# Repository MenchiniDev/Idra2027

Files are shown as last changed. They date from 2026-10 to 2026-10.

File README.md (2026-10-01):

# Idra di Guerra

Elettronica e meccanica per il carro **"Idra di Guerra"** — Carnevale di Viareggio.

## Obiettivi
- **PCB (KiCad)**: scheda EyeNode per ogni testa (servo degli occhi), alimentazione da 2 × 6 V piombo in serie (12 V).
- **Firmware**: ogni testa muove gli occhi in modo autonomo e casuale, senza sincronia tra le teste.
- **Requisiti elettrici**: budget energetico, dimensionamento alimentatori, sezione cavi, protezioni.
- **Meccanica 3D**: occhi (Ø ≥ 50 mm), incavo/orbita, meccanismo di movimento, supporto servo.
- **Chassis**: contenitori per l'elettronica, cablaggio ordinato e manutenibile.

## Struttura
```
docs/                  requisiti, budget energetico, cablaggio
hardware/kicad/        progetto KiCad (schematico + PCB)
hardware/datasheets/   datasheet componenti
mechanical/eyes/       original/ = modelli sorgente, scaled/ = occhi ingranditi
mechanical/enclosures/ chassis per l'elettronica
mechanical/scripts/    script di generazione/scalatura dei modelli
firmware/              codice delle schede EyeNode (movimento casuale autonomo)
```

## Regola chiave per gli occhi
Il bulbo va ingrandito a **diametro ≥ 50 mm**, ma la **sede del servo resta in scala 1:1**
(i servomotori sono fissi e non cambiano dimensione).

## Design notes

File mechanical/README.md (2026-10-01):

# Meccanica — Occhi animatronici

Base di partenza: **"Animatronic Eyes – Double and Single"** di *MorganManly*
([Instructables](https://www.instructables.com/Animatronic-Eyes-Double-and-Single-Fully-3D-Printe/),
[GitHub](https://github.com/ManlyMorgan/Animatronic-Eye)).
Licenza originale **CC BY-NC-SA 4.0** → vedi `docs/mechanical_eyes.md` § Licenza.

## Cartelle
| Cartella | Contenuto |
|---|---|
| `eyes/original/single_v4` | STL originali occhio singolo (Ø35 mm) |
| `eyes/original/double_compact` | STL originali doppio occhio |
| `eyes/scaled/D50`, `D70`, `D90` | occhi ingranditi Ø50 / Ø70 / Ø90 mm + `info.txt` con quote e viteria |
| `scripts/generate_eyes.py` | generatore parametrico (rigenera tutto, accetta diametri custom) |
| `enclosures/` | chassis elettronica (da fare) |

## Rigenerare
```bash
pip install trimesh manifold3d numpy scipy fast_simplification
python mechanical/scripts/generate_eyes.py          # 50, 70, 90
python mechanical/scripts/generate_eyes.py 60 80    # diametri a scelta
```

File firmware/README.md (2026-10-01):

# Firmware — EyeNode_random

Movimento **autonomo e casuale** degli occhi, uno sketch unico per tutte le teste.
Nessuna sincronizzazione: ogni testa vive per conto suo.

```
firmware/
  EyeNode_random/
    EyeNode_random.ino   logica (non serve toccarla)
    config.h             taratura: calibrazione servo, range, tempi, soglie
  sim/                   simulatore per PC (facoltativo, per provare modifiche senza hardware)
```

## Come rende diverse le teste
All'accensione ogni scheda calcola un **seme casuale** da: indirizzo DIP + contatore di accensioni
salvato in EEPROM + rumore degli ingressi analogici. Dal seme estrae il **carattere** della testa:

| Tratto | Range | Effetto |
|---|---|---|
| velocità | 0.80–1.25 × | quanto sono rapidi gli spostamenti |
| fissazione | 0.70–1.50 × | quanto resta a guardare un punto |
| battiti di ciglia | 0.70–1.40 × | frequenza |
| ampiezza sx/dx, su/giù | `RANGE_*_MIN…MAX` in `config.h` | quanto esplora |
| direzione preferita | ± `BIAS_*_MAX` | dove guarda "di solito" |
| curiosità | 0.25–0.60 | probabilità di grandi spostamenti invece di piccoli |
| convergenza (solo coppie) | 0–0.06 | occhi leggermente strabici verso l'interno |

Poi, ogni 1–4 minuti, cambia **umore**: *calmo* (lento, sguardo stretto), *curioso*, *agitato*
(rapido, fissazioni brevi, occhi sgranati), *assonnato* (palpebre basse, battiti lenti e lunghi).

Movimenti: fissazione con micro-movimenti → saccade (spostamento rapido con frenata finale), a volte
uno spostamento lento di "scansione"; battiti di ciglia casuali, a volte doppi, spesso dopo un grande
spostamento; le palpebre seguono lo sguardo (guardando in basso si abbassano un po').
I due occhi di una coppia guardano nello stesso punto, come occhi veri.

Quindi: due teste non fanno mai la stessa cosa, e la stessa testa a ogni accensione ha un carattere nuovo.

## Caricare il firmware
1. Arduino IDE → scheda **Arduino Nano**, processore **ATmega328P** (sui cloni economici: *Old Bootloader*).
2. Aprire `EyeNode_random/EyeNode_random.ino`, caricare. Librerie: solo `Servo` (inclusa nell'IDE).
3. Impostare il DIP della scheda (ON = 1): Testa 1 `0001`, Testa 2 `0010`, Testa 3 `0011`, Testa 4 `0100`.
   La Testa 4 (occhio singolo) usa solo le uscite A (D3, D5, D6).

Compilato e verificato: 13.4 KB flash (43 %), 713 B RAM (34 %).

## Taratura sul carro (una volta per testa)
1. Aprire il Monitor seriale a **115200**, inviare `c`: tutti i servo vanno al centro e le palpebre aperte.
   In questa posizione si montano squadrette, `LidCrank` e `HornExtender` (servo a 90°).
2. In `config.h`, tabella `CAL[indirizzo][occhio]`, per ogni servo impostare i microsecondi:
   - `lr`/`ud`: `{neg, mid, pos}` = posizione a −1 (sinistra/basso), centro, +1 (destra/alto);
   - `lid`: `{closed, open}`.
   Se un servo va al contrario, scambiare `neg` e `pos`. **Restare dentro la corsa libera**: un servo
   che spinge contro un fermo va in stallo, consuma ~0.8 A e scalda.
3. Ricaricare e inviare `r` per far ripartire il movimento casuale. `b` = battito di ciglia, `s` = stato
   (indirizzo, seme, carattere, umore, tensione servo).

Regolazioni utili in `config.h`:
- `RANGE_*` — ampiezza massima del movimento casuale;
- `FIX_*`, `BLINK_*` — ritmo di sguardi e battiti;
- `SPEED_SCALE` — rallentare tutto per i bulbi grandi (D90: ~0.8);
- `MICRO_AMP = 0` — elimina i micro-movimenti se i servo "ronzano".

## LED blu di stato (D12)
| Lampeggio | Significato |
|---|---|
| N lampi ogni 3 s | funzionamento normale, N = numero della testa |
| acceso fisso | modalità centro (`c`) |
| lampeggio rapido | tensione servo bassa (o batteria bassa, se misurata) |
| un lampo ogni 4 s | batteria scarica: occhi chiusi, servo staccati |

## Misura batteria (opzionale)
Per far "addormentare" la testa a batteria scarica: partitore **47 kΩ / 10 kΩ** dal +12 V al pin A6 del
connettore AUX (J11, pin 4), 10 kΩ verso GND; poi `#define BATT_SENSE_ENABLED 1` in `config.h`.
Soglie (piombo 12 V sotto carico): < 11.9 V umore assonnato, < 11.3 V per 10 s occhi chiusi e servo
staccati, riparte sopra 12.4 V. Non sostituisce il modulo LVD (la logica continua a consumare).

## Simulatore (facoltativo)
`sim/` compila lo stesso sketch sul PC con finti `Servo`/`EEPROM` e scrive le posizioni dei servo in CSV,
così si possono provare modifiche a `config.h` senza hardware. Serve un compilatore C++ (g++, clang o
`pip install ziglang`):
```bash
cd firmware/sim
python -m ziglang c++ -std=c++17 -O2 -w -I. -I../EyeNode_random -x c++ sim.cpp -o sim.exe
./sim.exe 1 123 300 > testa1.csv      # indirizzo, seme di prova, secondi simulati
python plot.py                         # rifà docs/img/simulazione_movimento_teste.png
```

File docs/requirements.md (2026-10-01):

# Requisiti — Idra di Guerra

> Bozza: i valori marcati **TBD** vanno confermati.

## Servomotori
| Voce | Valore |
|---|---|
| Modello servo | MG90S (metal gear) — SG90 sconsigliati |
| N. occhi | 7 (3 coppie + 1 singolo) → 21 servo, 4 schede EyeNode |
| Servo per occhio | 3 (sx/dx, su/giù, palpebre) |
| Tensione nominale | 4.8–6 V (alimentazione servo 6 V da DC-DC) |
| Movimento | autonomo e casuale per ogni testa, nessuna sincronia |
| Corrente di stallo per servo | ~0.7–1 A (da verificare su datasheet del lotto acquistato) |

## Alimentazione
- 2 batterie 6 V piombo **in serie** = 12 V, 30 Ah (AGM/VRLA consigliate).
- Fusibile generale entro 30 cm dal + batteria, fusibile da 5 A per ogni testa, protezione sottotensione.

## Budget energetico
- Corrente di picco = N_servo × I_stallo (dimensionare alimentatore su questo valore + 25% margine).
- Distribuzione per rami con fusibile dedicato.

## Cablaggio
- Sezione cavi in funzione di corrente e lunghezza (caduta di tensione < 3%).
- Connettori bloccabili (vibrazioni del carro), cavi segnale schermati sulle tratte lunghe.

## Ambiente
- Esterno, pioggia/umidità, vibrazioni: contenitori almeno IP54, PCB con conformal coating.

Lista della spesa: [lista_spesa.md](lista_spesa.md)

Dettagli completi (architettura, bilancio energetico, cavi, fusibili): [electronics.md](electronics.md)

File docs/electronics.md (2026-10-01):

# Elettronica — Idra di Guerra

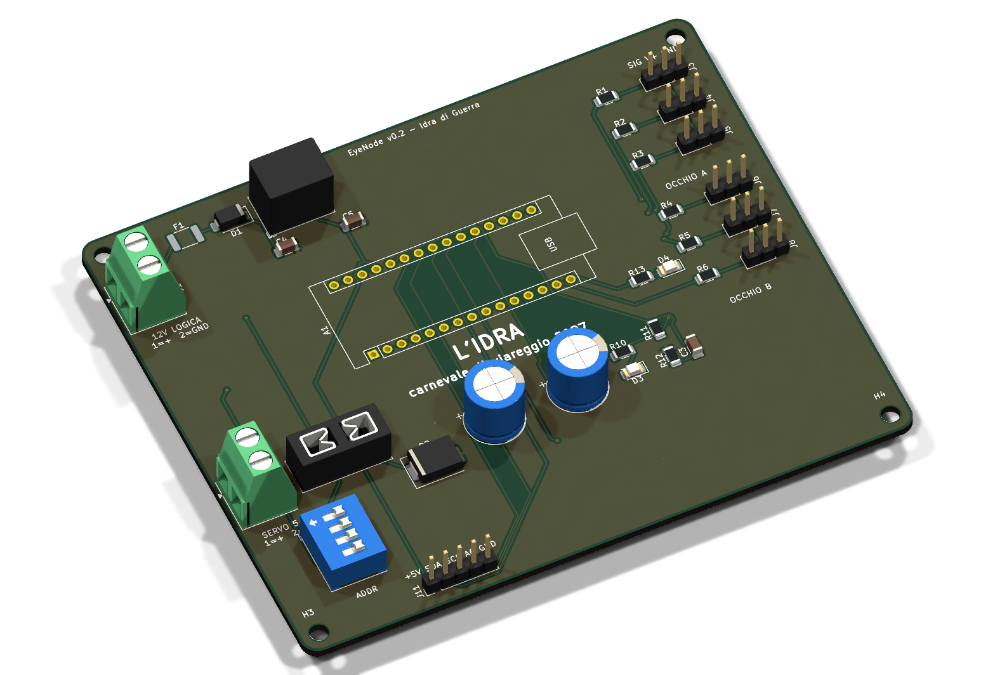
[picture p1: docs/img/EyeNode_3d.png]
EyeNode


## Architettura

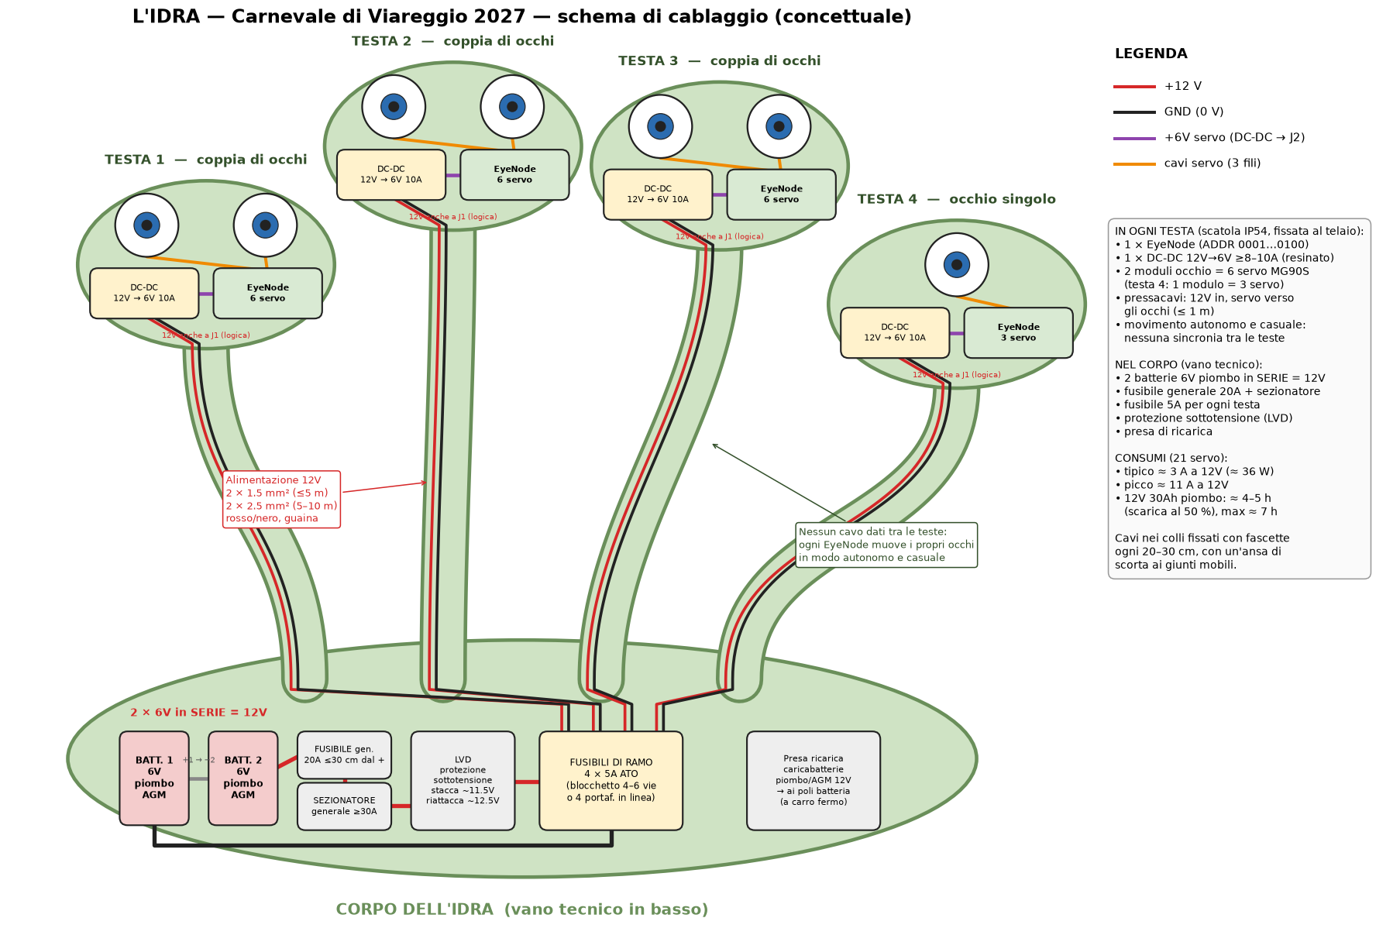
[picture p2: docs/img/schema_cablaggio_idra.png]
Schema di cablaggio


**7 occhi = 3 coppie + 1 singolo = 21 servo MG90S** (3 per occhio: sx/dx, su/giù, palpebre).

Una scheda **EyeNode** per ogni testa, montata vicino agli occhi (cavi servo corti). **Ogni testa è
autonoma**: muove i propri occhi in modo casuale, dentro un range, senza bus dati e senza master.
Il DIP switch serve solo a dire alla scheda quale testa è (coppia o singolo, calibrazione, seme casuale).

| Testa | Occhi | Servo | DIP ADDR |
|---|---|---|---|
| Testa 1 | coppia | 6 | 0001 |
| Testa 2 | coppia | 6 | 0010 |
| Testa 3 | coppia | 6 | 0011 |
| Testa 4 | singolo (solo canali A) | 3 | 0100 |

```
 BATT.1 6V ─(+)──(−)─ BATT.2 6V        ← in SERIE = 12 V
   (−)                    (+)
    │                      └──[F 20A]──[SEZIONATORE]──[LVD]──┬──[F 5A]──> Testa 1
    │                                                       ├──[F 5A]──> Testa 2
    │                                                       ├──[F 5A]──> Testa 3
    └──────────── GND comune ──────────────────────────────  └──[F 5A]──> Testa 4

 In ogni testa:  12V ──> J1 EyeNode (logica, R-78 → 5V)
                 12V ──> DC-DC 12V→6V 10A ──> J2 EyeNode (servo)
```

Perché così:
- **12 V sui cavi lunghi**, conversione a 6 V vicino ai servo: sui cavi lunghi la corrente è circa la metà,
  quindi cadute di tensione e sezioni dei cavi restano contenute.
- **Logica separata dai servo**: l'Arduino ha il suo regolatore (R-78E5.0), quindi i picchi dei servo
  non lo resettano. Le masse sono comuni sulla scheda.
- **Nessuna sincronia**: niente cavo dati nei colli. Un guasto in una testa non tocca le altre.

## Batteria: 2 × 6 V al piombo in serie

> ⚠️ **Serie, non parallelo.** Per ottenere 12 V da due batterie da 6 V vanno collegate **in serie**:
> il **+** della batteria 1 al **−** della batteria 2; si preleva il **−** dalla batteria 1 e il **+** dalla batteria 2.
> In **parallelo** (+ con +, − con −) la tensione resta **6 V** e si raddoppia solo la capacità: con 6 V il
> regolatore della logica (R-78E5.0, minimo 7 V) e i DC-DC 12→6 V non funzionano.
>
> Capacità: in serie la capacità è quella di **una** batteria. Due 6 V **30 Ah** in serie = **12 V 30 Ah**
> (due 6 V 15 Ah in serie farebbero 12 V 15 Ah). I calcoli qui sotto assumono **12 V 30 Ah** totali.

| Voce | Valore |
|---|---|
| Configurazione | 2 × 6 V piombo, **in serie** → 12 V nominali |
| Capacità | 30 Ah (C20) |
| Tipo consigliato | **AGM / VRLA sigillate** (niente acido libero: il carro si inclina e vibra) |
| Tensione utile | 12.7 V carica a riposo · ≈ 12.0 V al 50 % · non scendere sotto ≈ 11.5 V sotto carico |
| Ponticello serie | cavo corto 4 mm² con capicorda, morsetti protetti |
| Ricarica | caricabatterie **12 V piombo/AGM** (assorbimento 14.4–14.7 V, mantenimento 13.6–13.8 V), sulle due in serie |

### Autonomia (stima)
| | Corrente a 12 V | Note |
|---|---|---|
| Consumo tipico (21 servo in movimento casuale + 4 schede) | ≈ 3 A | stima prudente: gran parte del tempo gli occhi sono fermi a fissare |
| Picco (tutti i servo in stallo) | ≈ 11 A | caso limite; 0.37 C, la batteria lo regge |
| Energia utilizzabile al 50 % (consigliato per la durata del piombo) | ≈ 13–15 Ah | → **≈ 4–5 h** |
| Massimo assoluto (80 %) | ≈ 22 Ah | → **≈ 7 h**, ma accorcia molto la vita della batteria |

Regole per il piombo:
- **Ricaricare subito dopo ogni uscita**: lasciata scarica si solfata e perde capacità in pochi giorni.
- Le due batterie devono essere **uguali** (stesso modello, stessa età); in serie, quella più debole si
  scarica per prima. Ogni tanto controllare che le due tensioni siano simili (differenza < 0.1 V a riposo).
- Montarle fisse, in piano, lontano da scintille; le AGM non vanno caricate oltre 14.7 V.
- **Protezione sottotensione (LVD)**: un modulo 12 V da ≥ 20 A che stacca il carico a ≈ 11.5 V e lo
  riattacca a ≈ 12.5 V evita di scaricare a fondo le batterie se il carro resta acceso. In alternativa
  (o in più) il firmware può leggere la batteria su A6 con un partitore (vedi `firmware/README.md`):
  in quel caso a batteria scarica la testa chiude gli occhi e stacca i servo, ma la logica continua a
  consumare qualche decina di mA, quindi non sostituisce l'LVD.

## Serve la scatola dei fusibili?

Risposta breve: **il fusibile generale è obbligatorio, i fusibili per ogni testa sono fortemente consigliati,
la "scatola" è solo il modo più comodo di montarli** — non è indispensabile.

1. **Fusibile generale vicino alla batteria — sì, sempre.** Una batteria al piombo in cortocircuito
   eroga centinaia di ampere: senza fusibile un cavo schiacciato o spellato diventa una resistenza
   incandescente dentro un carro di cartapesta e legno con persone sopra. Va montato entro **30 cm dal
   polo +**, prima di tutto il resto (anche del sezionatore). 20 A per il cavo principale da 4 mm².
2. **Un fusibile per ogni testa — sì, ed ecco perché.** Il fusibile da 20 A protegge il cavo da 4 mm²,
   ma i rami che salgono nei colli sono da 1.5 mm²: un corto lungo un collo potrebbe far passare fino a
   20 A in un cavo da 1.5 mm² chiuso in un fascio, che si scalda ben prima che il 20 A intervenga.
   Il fusibile da 5 A per ramo protegge quel cavo e, in più, **se una testa si guasta si spegne solo
   quella**: le altre tre continuano a muoversi per tutta la sfilata.
3. **Il fusibile sulla scheda (F2, 7.5 A) non basta**: sta *dopo* il DC-DC, quindi protegge il lato 6 V
   dei servo ma non il cavo 12 V che sale nel collo.
4. **Scatola o no?** Con 4 rami bastano 4 **portafusibili in linea stagni** (ATO, pochi euro l'uno). Un
   blocchetto fusibili a 4–6 vie fa la stessa cosa ma è più ordinato: un unico punto da ispezionare,
   ricambi a portata di mano, cablaggio più pulito nel vano tecnico. È una scelta di comodità.
5. L'unico modo di farne a meno sarebbe portare il 4 mm² fino a ogni testa (più rame, più peso, e un
   guasto in una testa spegne tutto). Non conviene.

## Scheda EyeNode v0.2 (`hardware/kicad/EyeNode`)
- 110 × 90 mm, 2 strati, fori M3 agli angoli. **Rame consigliato 2 oz (70 µm)** per le piste servo.
- Arduino Nano v3 su strip femmina (sostituibile, programmabile via USB a bordo).
- 6 uscite servo (header 2.54 mm, ordine **SIG – V+ – GND**, GND verso il bordo):
  `D3 D5 D6` = occhio A (sx/dx, su/giù, palpebre), `D9 D10 D11` = occhio B. Resistenza da 220 Ω in serie su ogni segnale.
- J1: 12 V logica (7–28 V), polyfuse 0.5 A + diodo anti-inversione.
- J2: alimentazione servo 5–6 V, fusibile a lama mini 7.5 A, diodo SS54 di protezione da inversione
  di polarità (fa saltare il fusibile), 2 × 1000 µF.
- VSERVO misurata su A7 (partitore 1:2), LED verde VSERVO, LED blu di stato su D12
  (lampeggia N volte ogni 3 s, N = numero della testa).
- DIP 4 bit su A0–A3 = indirizzo testa. Header AUX: +5V, SDA (A4), SCL (A5), A6, GND
  (A6 = misura batteria opzionale, oppure sensori).
- **v0.2: rimossi MAX485, terminazione 120 Ω, jumper JP1 e morsetti RS-485 IN/OUT** (nessuna sincronia).
  D4, D7, D8 restano liberi.
- Verifiche: ERC 0 errori; DRC 0 errori, 0 connessioni mancanti, parità schema↔PCB ok;
  restano solo 3 avvisi di serigrafia (testo "SERVO 5-6V" vicino al DIP switch).

File di produzione in `hardware/kicad/EyeNode/fab/`: `EyeNode_gerber_JLCPCB.zip` (Gerber + forature),
`EyeNode_BOM.csv`, `EyeNode_pos.csv`, schema PDF, render.

Rigenerare tutto (schema → netlist → PCB → autorouting → piani di massa):
```bash
cd hardware/kicad/scripts
python gen_sch.py
kicad-cli sch export netlist -o ../EyeNode/EyeNode.net ../EyeNode/EyeNode.kicad_sch
"C:/Program Files/KiCad/10.0/bin/python.exe" gen_pcb.py
"C:/Program Files/KiCad/10.0/bin/python.exe" route.py     # Freerouting 2.1 (Java 21)
"C:/Program Files/KiCad/10.0/bin/python.exe" add_logo_text.py
```

## Firmware
`firmware/EyeNode_random/` — stesso sketch su tutte le schede, movimento casuale e indipendente per
ogni testa. Dettagli, taratura e comandi in [firmware/README.md](../firmware/README.md).

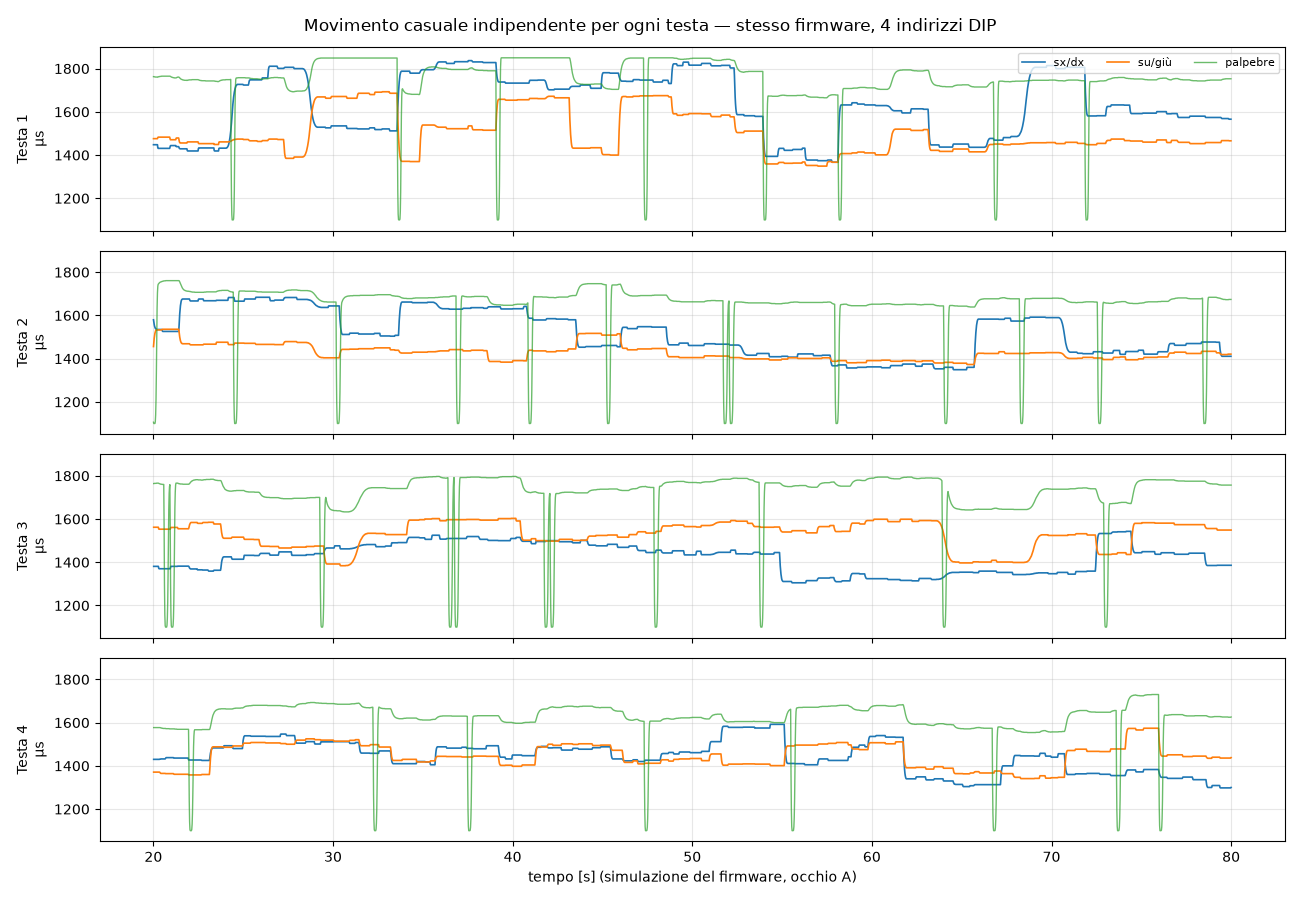
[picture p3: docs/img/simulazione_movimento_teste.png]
Simulazione


## Bilancio energetico
MG90S (datasheet tipico, da verificare sul lotto): ~10 mA a riposo, 150–250 mA in movimento senza carico,
**stallo ~0.7–0.9 A** a 4.8–6 V.

| | Tipico (movimento) | Picco (tutti in stallo) |
|---|---|---|
| 1 servo | 0.25 A | 0.9 A |
| EyeNode coppia (6 servo) | 1.5 A | 5.4 A |
| EyeNode singolo (3 servo) | 0.75 A | 2.7 A |
| **Totale 21 servo, lato 6 V** | **≈ 5 A (30 W)** | **≈ 19 A (113 W)** |
| Totale lato 12 V (η ≈ 90 %, + logica 4 × 50 mA) | ≈ 3 A | ≈ 11 A |

Lo stallo simultaneo di tutti i servo è un caso limite (non accade nel movimento normale), ma
alimentatori e fusibili sono dimensionati comunque per reggerlo. Il firmware aggancia i servo uno alla
volta e fa partire le teste sfasate, così all'accensione non c'è un unico grande spunto.

### Componenti di potenza
| Voce | Specifica | Q.tà |
|---|---|---|
| Batterie | 6 V 30 Ah piombo AGM/VRLA, **collegate in serie** | 2 |
| Ponticello serie | cavo 4 mm² corto con capicorda | 1 |
| Fusibile generale | 20 A a lama ATO/MIDI, portafusibile stagno, **≤ 30 cm dal +** | 1 |
| Sezionatore generale | ≥ 30 A, stagno | 1 |
| Protezione sottotensione (LVD) | 12 V, ≥ 20 A, stacco ≈ 11.5 V / riattacco ≈ 12.5 V | 1 |
| Fusibili di ramo | 5 A ATO: blocchetto 4–6 vie **oppure** 4 portafusibili in linea stagni | 4 |
| DC-DC per testa | 12 V → 6.0 V (oppure 5.0 V), **≥ 8–10 A**, ingresso almeno 9–16 V, resinato/IP67 (tipo automotive) | 4 |
| Fusibile servo sulla scheda | 7.5 A a lama mini (testa singola: 5 A) | 4 |
| Caricabatterie | 12 V piombo/AGM, 3–6 A, con mantenimento | 1 |

### Sezione cavi (rame, caduta di tensione ≤ 5 % andata + ritorno)
| Tratta | Corrente di progetto | Lunghezza | Sezione |
|---|---|---|---|
| Batteria → fusibili di ramo (e ponticello serie) | 11 A | fino a 5 m | **4 mm²** |
| Ramo 12 V → testa | 3 A | ≤ 5 m | **1.5 mm²** |
| Ramo 12 V → testa | 3 A | 5–10 m | **2.5 mm²** |
| DC-DC → J2 (servo) | 6 A | ≤ 0.5 m | **1.5 mm²** |
| Prolunghe servo | 1 A | ≤ 1 m | cavo servo standard 22 AWG (0.33 mm²) |
| Prolunghe servo | 1 A | 1–2 m | 0.5 mm², segnale intrecciato con GND |

Regole di cablaggio: puntalini su tutti i morsetti; connettori bloccabili per le parti mobili del carro;
cavi fissati e protetti nelle zone soggette a vibrazioni; schede in contenitore IP54 con pressacavi.

## Da fare
- [ ] Contenitore stampato 3D per EyeNode + DC-DC (con pressacavi)
- [x] Firmware autonomo casuale (`firmware/EyeNode_random`)
- [ ] Taratura sul carro: limiti meccanici di ogni occhio in `config.h`
- [ ] Verifica corrente di stallo reale dei MG90S acquistati e taratura fusibili
- [ ] Verificare la capacità della singola batteria da 6 V (30 Ah ciascuna → 12 V 30 Ah in serie)

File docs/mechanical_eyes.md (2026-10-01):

# Occhi animatronici ingranditi — note di progetto

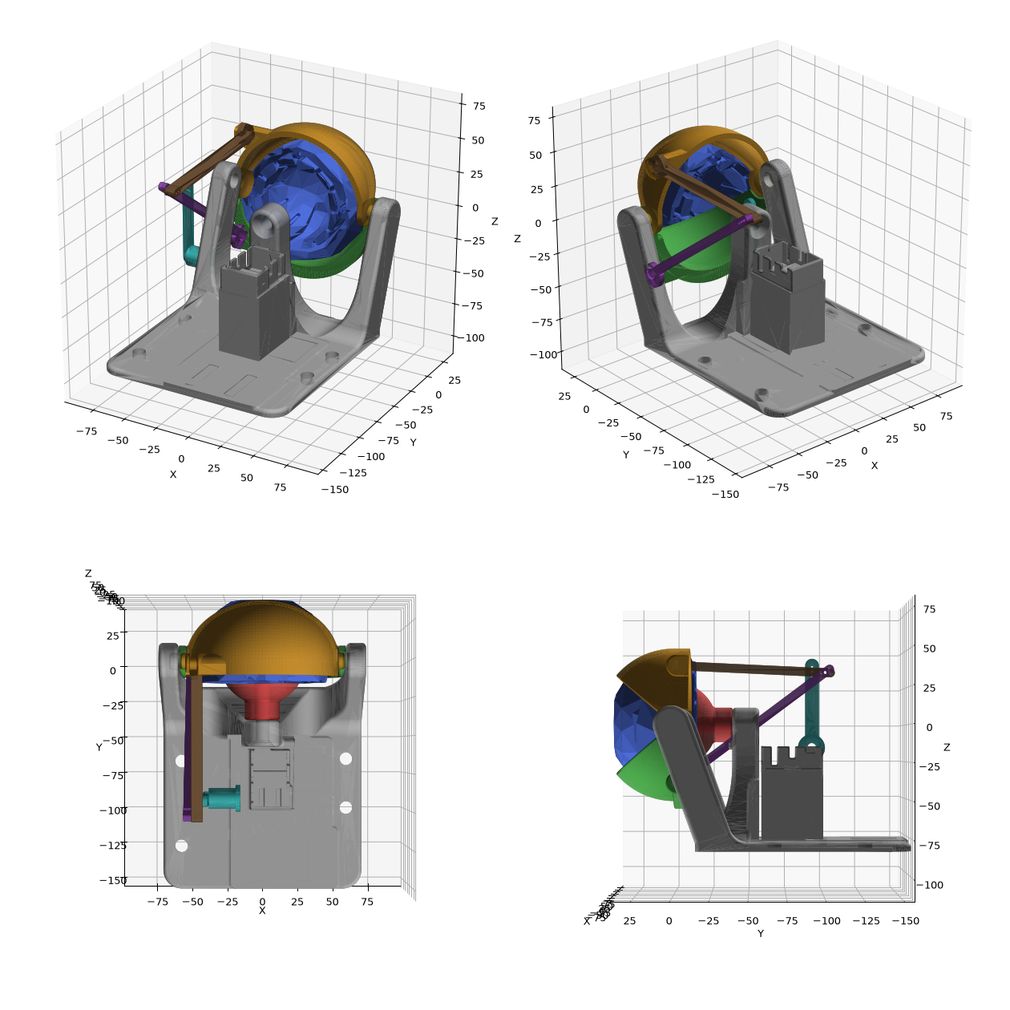
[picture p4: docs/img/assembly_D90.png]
D90


## Cosa viene scalato e cosa no
Fattore `k = D / 35` (D50 → 1.43, D70 → 2.00, D90 → 2.57), centro di scala = centro occhio.

| Pezzo | Trattamento |
|---|---|
| Bulbo, snodo sferico, palpebre sup./inf. | scalati uniformemente di k |
| BasePlate: piastra, montanti palpebre, torre snodo | scalati di k |
| **BasePlate: vano servo** | **1:1 originale**, ritagliato e trapiantato dietro la torre, alla stessa quota rispetto al centro occhio, su un piedistallo |
| Tiranti palpebre | rigenerati: testa d'innesto scalata + corpo dritto + 3 fori di regolazione (±3 mm) |
| `LidCrank` (nuovo) | prolunga per la squadretta del servo palpebre: braccio di raggio k·r, così gli angoli servo restano quelli originali |
| `HornExtender` (nuovo) | prolunga per le squadrette dei 2 servo occhio, fila di fori ogni 2.5 mm per il filo |

Perché le prolunghe: con servo e squadrette 1:1 e leve sull'occhio k volte più grandi, la stessa
corsa del servo darebbe un angolo dell'occhio k volte minore. Allungando il braccio di k la
cinematica torna simile all'originale e la calibrazione (`calibration.ino`) resta valida come punto di partenza.

## Viteria e materiali per taglia
| | D50 | D70 | D90 |
|---|---|---|---|
| Vite snodo (orig. M3) | M4 + inserto M4 | M6 + inserto M6 | M8 + inserto M8 |
| Foro inserto nello snodo | 5.9 mm | 8.2 mm | 10.5 mm |
| Fori fissaggio piastra | 5.0 mm | 7.0 mm | 9.0 mm |
| Filo armonico occhio (orig. 1 mm) | 1.5 mm | 2.0 mm | 2.5 mm |
| Tiranti palpebre ↔ LidCrank | viti M2 | viti M2 | viti M2 |
| Raggio braccio palpebre | 27.9 mm | 39.1 mm | 50.2 mm |
| Ingombro BasePlate (X×Y×Z) | 77×94×53 | 108×131×74 | 138×168×95 |

La zona libera della piastra dietro al vano servo (molto ampia in D70/D90) è pensata per il
fissaggio della scheda di controllo.

## Montaggio — differenze rispetto all'originale
1. Servo, squadrette e vano: identici all'originale (MG90S consigliati).
2. Centrare i servo a 90° **prima** di montare le prolunghe (come da istruzioni originali).
3. `LidCrank`: appoggiarlo sulla squadretta del servo palpebre, forare Ø1.5 attraverso i fori della
   squadretta e fissare con 2 viti M2 autofilettanti; foro centrale Ø6.4 per la vite della squadretta.
   A 90° il braccio deve puntare verso l'alto.
4. Tiranti: una vite M2 lunga attraversa tirante inferiore, tirante superiore e braccio. Scegliere la
   coppia di fori (tirante/braccio) che dà palpebre centrate a servo a 90°.
5. `HornExtender`: stesso fissaggio sulla squadretta; il filo va nel foro al raggio ≈ k × raggio usato in origine.

## Da verificare con la prima stampa (consigliato: D50)
- Asse del servo palpebre stimato da foto e geometria (`LID_SERVO_AXIS` nello script): i fori di
  regolazione compensano ±3 mm, ma va confermato.
- Le tolleranze di stampa si scalano con k (giochi più ampi nelle taglie grandi): verificare
  l'innesto a scatto bulbo–snodo e palpebre–montanti.
- Coppia: con D90 i bulbi pesano ~5-6 volte l'originale; gli MG90S (2.2 kg·cm) restano nel margine
  per movimenti fluidi, ma evitare scatti troppo bruschi (ServoEasing).

## Licenza
Il progetto originale è **CC BY-NC-SA 4.0** (attribuzione, **non commerciale**, condividi allo stesso
modo). I file derivati qui sono soggetti alla stessa licenza. Un carro allegorico ha
un contesto commerciale/professionale: **chiedere il permesso all'autore (MorganManly)** prima dell'uso sul carro,
oppure ridisegnare da zero i pezzi.

## Versione COPPIA (double)
File in `mechanical/eyes/scaled/double/D50|D70|D90/`. Anteprima: `docs/img/confronto_taglie_coppia.png`.

- Base dalla versione "double compact" originale: due vani servo 1:1 (sx e dx speculare), vano
  centrale (supporti protoboard + foro connettore alimentazione) scalato di k.
- Pezzi `_x2` / `_x4` = da stampare 2 / 4 volte (bulbo, snodo, prolunghe squadrette).
- Pezzi `_L` / `_R` = occhio sinistro / destro (palpebre, tiranti, LidCrank speculari).

| | D50 | D70 | D90 |
|---|---|---|---|
| Interasse occhi | 94.0 mm | 131.6 mm | 169.2 mm |
| Ingombro BasePlate_Double (X×Y×Z) | 171×94×53 | 239×131×74 | **308**×168×95 |

⚠️ La BasePlate_Double D90 (308 mm) non entra nei piatti comuni (220–256 mm): va divisa in due
metà con giunzione (posso generarla con incastro a coda di rondine + viti) oppure si usano due
moduli singoli affiancati. La D70 (239 mm) entra in piatti da 256 mm (es. Bambu X1/P1).

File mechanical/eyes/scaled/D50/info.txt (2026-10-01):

diametro_mm: 50
k: 1.4286
spostamento_vano_servo_y_mm: -13.93
asse_servo_palpebre_yz: [-66.93, -15.5]
tirante_sup_mm: 70.5
tirante_inf_mm: 77.4
raggio_braccio_palpebre_mm: 27.9
vite_snodo: M4
inserto_snodo_foro_mm: 5.9
fori_piastra_mm: 5.0
perno_palpebra_mm: 5.7
filo_occhio_mm: 1.5

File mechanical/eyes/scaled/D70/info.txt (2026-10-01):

diametro_mm: 70
k: 2.0
spostamento_vano_servo_y_mm: -26.5
asse_servo_palpebre_yz: [-79.5, -15.5]
tirante_sup_mm: 83.9
tirante_inf_mm: 99.0
raggio_braccio_palpebre_mm: 39.1
vite_snodo: M6
inserto_snodo_foro_mm: 8.2
fori_piastra_mm: 7.0
perno_palpebra_mm: 8.0
filo_occhio_mm: 2.0

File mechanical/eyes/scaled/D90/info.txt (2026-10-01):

diametro_mm: 90
k: 2.5714
spostamento_vano_servo_y_mm: -39.07
asse_servo_palpebre_yz: [-92.07, -15.5]
tirante_sup_mm: 97.4
tirante_inf_mm: 121.4
raggio_braccio_palpebre_mm: 50.2
vite_snodo: M8
inserto_snodo_foro_mm: 10.5
fori_piastra_mm: 9.0
perno_palpebra_mm: 10.3
filo_occhio_mm: 2.5

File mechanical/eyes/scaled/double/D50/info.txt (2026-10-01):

diametro_mm: 50
k: 1.4286
interasse_occhi_mm: 94.0
spostamento_vani_servo_y_mm: -13.93
tirante_sup_mm: 70.5
tirante_inf_mm: 77.4
raggio_braccio_palpebre_mm: 27.9
vite_snodo: M4
inserto_snodo_foro_mm: 5.9
fori_piastra_mm: 5.0
perno_palpebra_mm: 5.7
filo_occhio_mm: 1.5

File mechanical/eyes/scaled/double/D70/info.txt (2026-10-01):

diametro_mm: 70
k: 2.0
interasse_occhi_mm: 131.6
spostamento_vani_servo_y_mm: -26.5
tirante_sup_mm: 83.9
tirante_inf_mm: 99.0
raggio_braccio_palpebre_mm: 39.1
vite_snodo: M6
inserto_snodo_foro_mm: 8.2
fori_piastra_mm: 7.0
perno_palpebra_mm: 8.0
filo_occhio_mm: 2.0

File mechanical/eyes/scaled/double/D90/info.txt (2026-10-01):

diametro_mm: 90
k: 2.5714
interasse_occhi_mm: 169.2
spostamento_vani_servo_y_mm: -39.07
tirante_sup_mm: 97.4
tirante_inf_mm: 121.4
raggio_braccio_palpebre_mm: 50.2
vite_snodo: M8
inserto_snodo_foro_mm: 10.5
fori_piastra_mm: 9.0
perno_palpebra_mm: 10.3
filo_occhio_mm: 2.5

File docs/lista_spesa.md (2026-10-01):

# Lista della spesa — L'Idra 2027

Per 4 teste (3 coppie + 1 singolo = 7 occhi, 21 servo), alimentazione 2 × 6 V piombo in serie.
Le quantità includono già qualche **ricambio** (colonna "di cui ricambi").
Prezzi = **stima indicativa** in €, IVA inclusa, da negozi online tipo Amazon/AliExpress/elettronica
generica: servono per farsi un'idea del budget, non sono preventivi.

> **Cavi: lunghezze stimate.** Ho assunto ≤ 5 m dal vano tecnico a ogni testa. Prima di comprare
> misurare il percorso reale di ogni collo (+ 1 m di scorta). Se un collo supera i 5 m, quel ramo va
> in 2 × 2.5 mm² invece di 2 × 1.5 mm².

## 1. Alimentazione (vano tecnico nel corpo)
| # | Articolo | Specifica | Q.tà | di cui ricambi | € stima |
|---|---|---|---|---|---|
| 1 | Batterie | 6 V 30 Ah piombo AGM/VRLA, **già disponibili** — da collegare in **serie** | 2 | — | — |
| 2 | Portafusibile generale stagno | per fusibile a lama ATO (o MIDI), con cavo 4 mm² | 1 | — | 6–10 |
| 3 | Fusibili ATO 20 A | lama standard | 3 | 2 | 3 |
| 4 | Sezionatore generale | stacca-batteria rotativo ≥ 30 A, stagno | 1 | — | 15–25 |
| 5 | Modulo LVD (protezione sottotensione) | 12 V, ≥ 20 A, stacco ~11.5 V / riattacco ~12.5 V, regolabile | 1 | — | 15–25 |
| 6 | Blocco fusibili | 6 vie ATO **con barra negativa integrata** e coperchio (tipo nautico) — *oppure* 4 portafusibili ATO in linea stagni | 1 | — | 15–25 |
| 7 | Fusibili ATO 5 A | rami verso le teste | 8 | 4 | 3 |
| 8 | Caricabatterie | 12 V piombo/AGM, 3–6 A, con mantenimento | 1 | — | 30–50 |
| 9 | Presa di ricarica (opz.) | presa stagna 2 poli (tipo SAE o Anderson 50 A) da pannello | 1 | — | 5–10 |
| 10 | Scatola vano tecnico | IP65 ~300 × 200 × 150 mm, o cassetta batterie con cinghie | 1 | — | 20–35 |

## 2. Elettronica in ogni testa
| # | Articolo | Specifica | Q.tà | di cui ricambi | € stima |
|---|---|---|---|---|---|
| 11 | Convertitore DC-DC | 12 V → 6 V, **≥ 10 A**, ingresso almeno 9–16 V, resinato/impermeabile | 5 | 1 | 50–75 |
| 12 | Servo MG90S | **metal gear** (non SG90) | 25 | 4 | 75–100 |
| 13 | Prolunghe servo | 3 fili JR/Futaba, 30–50 cm (misurare dalla scheda agli occhi) | 25 | 4 | 10–15 |
| 14 | Fusibili a lama **mini** 7.5 A | per F2 sulla scheda (teste 1–3) | 6 | 3 | 2 |
| 15 | Fusibili a lama **mini** 5 A | per F2 sulla scheda (testa 4) | 2 | 1 | 1 |
| 16 | Scatola per scheda + DC-DC | IP65 ~150 × 120 × 70 mm (o contenitore stampato 3D) | 4 | — | 25–40 |
| 17 | Pressacavi | PG7 (cavi servo) + PG9 (alimentazione), kit assortito | 1 kit | — | 8 |
| 18 | Morsetti a leva Wago 221-413 | per dividere il 12 V tra DC-DC e J1 nella testa | 10 | 2 | 6 |

## 3. Scheda EyeNode (componenti per 5 schede: 4 + 1 ricambio)
| # | Articolo | Rif. | Footprint / tipo | Q.tà | € stima |
|---|---|---|---|---|---|
| 19 | PCB EyeNode v0.2 | — | JLCPCB, 2 strati, **rame 2 oz**, 110 × 90 mm (file `fab/EyeNode_gerber_JLCPCB.zip`) | 5 (minimo ordine) | 25–45 con spedizione |
| 20 | Arduino Nano v3 | A1 | ATmega328P, USB mini-B o C | 5 | 25–40 |
| 21 | Strip femmina 1 × 15, passo 2.54 | per A1 | per rendere il Nano estraibile | 10 | 3 |
| 22 | Regolatore RECOM R-78E5.0-0.5 | U1 | THT SIP3 | 5 | 20 |
| 23 | Condensatore elettrolitico 1000 µF **16 V** low-ESR | C1, C2 | radiale Ø10 mm, passo 5 mm | 10 | 5 |
| 24 | Condensatore ceramico 100 nF | C3 | SMD 1206 | 10 | 1 |
| 25 | Condensatore ceramico 10 µF 50 V | C4 | SMD 1206 | 10 | 2 |
| 26 | Condensatore ceramico 10 µF 16 V | C5 | SMD 1206 | 10 | 1 |
| 27 | Diodo Schottky SS34 | D1 | SMA | 10 | 1 |
| 28 | Diodo Schottky SS54 | D2 | SMC | 10 | 2 |
| 29 | LED verde | D3 | SMD 1206 | 10 | 1 |
| 30 | LED blu | D4 | SMD 1206 | 10 | 1 |
| 31 | Polyfuse 0.5 A | F1 | SMD 1812 | 10 | 2 |
| 32 | Portafusibile lama mini Keystone 3568 | F2 | THT | 5 | 6 |
| 33 | Morsetto a vite 2 poli passo 5.08 (Phoenix MKDS 1,5/2) | J1, J2 | THT | 10 | 4 |
| 34 | Strip maschio 1 × 40, passo 2.54 | J3–J8, J11 | da tagliare a 3 e 5 pin | 5 | 2 |
| 35 | Resistenza 220 Ω | R1–R6 | SMD 1206 | 50 | 1 |
| 36 | Resistenza 1 kΩ | R10, R13 | SMD 1206 | 20 | 1 |
| 37 | Resistenza 10 kΩ | R11, R12 | SMD 1206 | 20 | 1 |
| 38 | DIP switch 4 vie | SW1 | THT passo 2.54 | 5 | 3 |
| 39 | Distanziali M3 10 mm + viti | fori angoli | nylon o ottone | 20 | 4 |

*Facoltativo, misura batteria nel firmware:* resistenze 47 kΩ e 10 kΩ (¼ W), 5 + 5.
*Alternativa:* far montare i componenti SMD direttamente a JLCPCB (servizio di assemblaggio) usando
`EyeNode_BOM.csv` e `EyeNode_pos.csv`; restano da saldare a mano solo i componenti a foro passante.

## 4. Cavi e materiale di cablaggio
| # | Articolo | Specifica | Q.tà | Uso | € stima |
|---|---|---|---|---|---|
| 40 | Cavo unipolare **4 mm²** rosso | flessibile (FS17/H07V-K) | 3 m | batteria → fusibile → sezionatore → LVD → blocco fusibili | 5 |
| 41 | Cavo unipolare **4 mm²** nero | flessibile | 3 m | ritorno negativo + **ponticello serie** tra le batterie | 5 |
| 42 | Cavo bipolare **2 × 1.5 mm²** rosso/nero | piattina o cavo con guaina (FROR) | 25 m | 4 rami da ~5 m verso le teste + DC-DC → J2 | 25–35 |
| 43 | Cavo bipolare 2 × 2.5 mm² | solo se un collo supera 5 m | a misura | ramo lungo | — |
| 44 | Cavo 3 × 0.5 mm² (o prolunghe servo da 1–2 m) | solo se un servo è a più di 1 m dalla scheda | a misura | prolunghe lunghe | — |
| 45 | Capicorda ad occhiello 4 mm² | foro adatto ai poli batteria e al sezionatore (M5/M6/M8, verificare) | 10 | poli batteria, sezionatore | 3 |
| 46 | Faston femmina isolati 6.3 mm, 4 mm² | solo se le batterie hanno poli faston | 6 | poli batteria | 2 |
| 47 | Puntalini isolati | kit assortito 0.5 – 4 mm² | 1 kit | tutti i morsetti a vite | 8 |
| 48 | Connettori stagni 2 poli, maschio + femmina | tipo Superseal / Deutsch DT, per 1.5 mm² | 5 coppie | staccare ogni testa alla base del collo | 12–20 |
| 49 | Guaina termorestringente | kit assortito, con colla | 1 kit | giunzioni e connettori | 8 |
| 50 | Tubo corrugato spiralato | Ø 10–13 mm | 20 m | protezione cavi nei colli | 10–15 |
| 51 | Fascette | 200 mm + 300 mm, nere anti-UV | 200 | fissaggio cavi ogni 20–30 cm | 6 |
| 52 | Basette per fascette | adesive o a vite | 50 | punti di fissaggio sul telaio | 5 |
| 53 | Cavo USB (mini-B o C, come i Nano) | — | 1 | programmazione | 3 |

## 5. Meccanica occhi (dipende dalla taglia scelta)
| # | Articolo | D50 | D70 | D90 | Q.tà |
|---|---|---|---|---|---|
| 54 | Filamento PETG (o PLA+) | ~1 kg | ~2 kg | ~3 kg | — |
| 55 | Vite snodo + inserto filettato a caldo | M4 | M6 | M8 | 7 + 3 ricambi |
| 56 | Filo armonico (acciaio) per tiranti occhio | Ø 1.5 mm | Ø 2.0 mm | Ø 2.5 mm | 2 m |
| 57 | Viti M2 autofilettanti 8–12 mm | per LidCrank, HornExtender, tiranti palpebre | | | 100 |
| 58 | Viti fissaggio piastre al telaio | Ø foro 5 / 7 / 9 mm | | | 30 |

## Riepilogo budget indicativo
| Gruppo | € stima |
|---|---|
| 1. Alimentazione (batterie escluse) | ~110–185 |
| 2. Elettronica teste | ~175–245 |
| 3. Scheda EyeNode × 5 | ~110–150 |
| 4. Cavi e cablaggio | ~90–115 |
| 5. Meccanica (D70) | ~50–80 |
| **Totale** | **~545–775 €** |

## Attrezzi (se mancano)
Saldatore con punta fine + stagno 0.5 mm e flussante; **crimpatrice** per capicorda e puntalini;
spelafili; pistola termica; multimetro; stampante 3D.

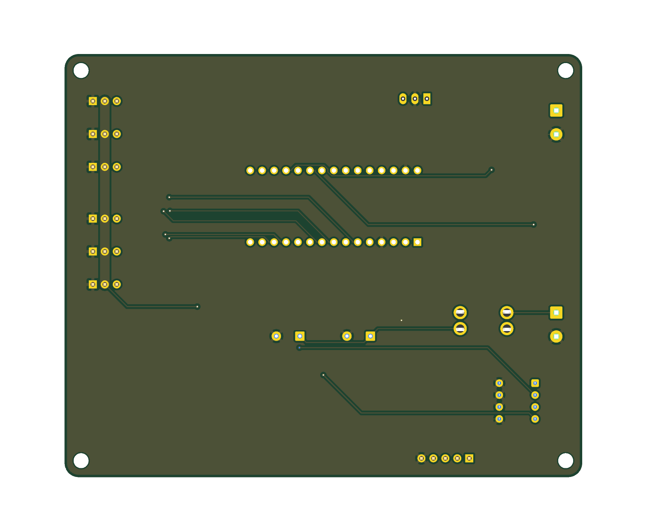
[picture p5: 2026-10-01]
hardware/kicad/EyeNode/fab/EyeNode_bottom.png

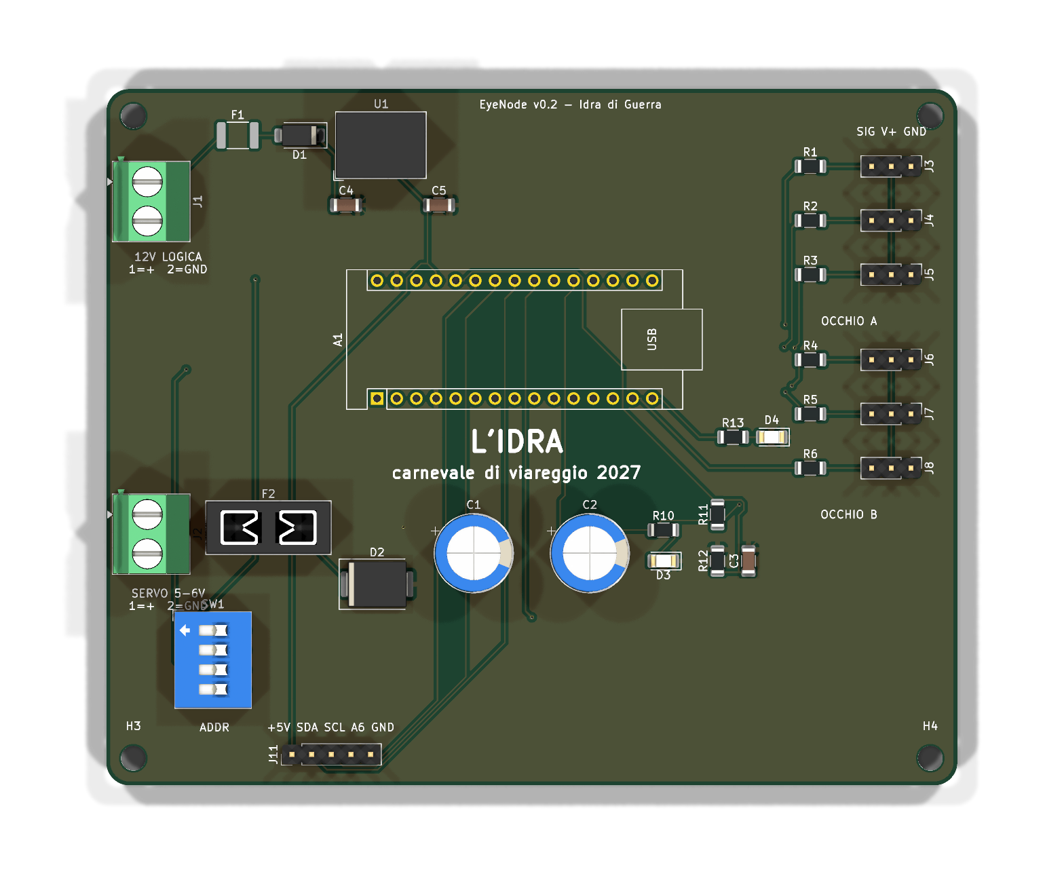
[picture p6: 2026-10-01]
hardware/kicad/EyeNode/fab/EyeNode_top.png

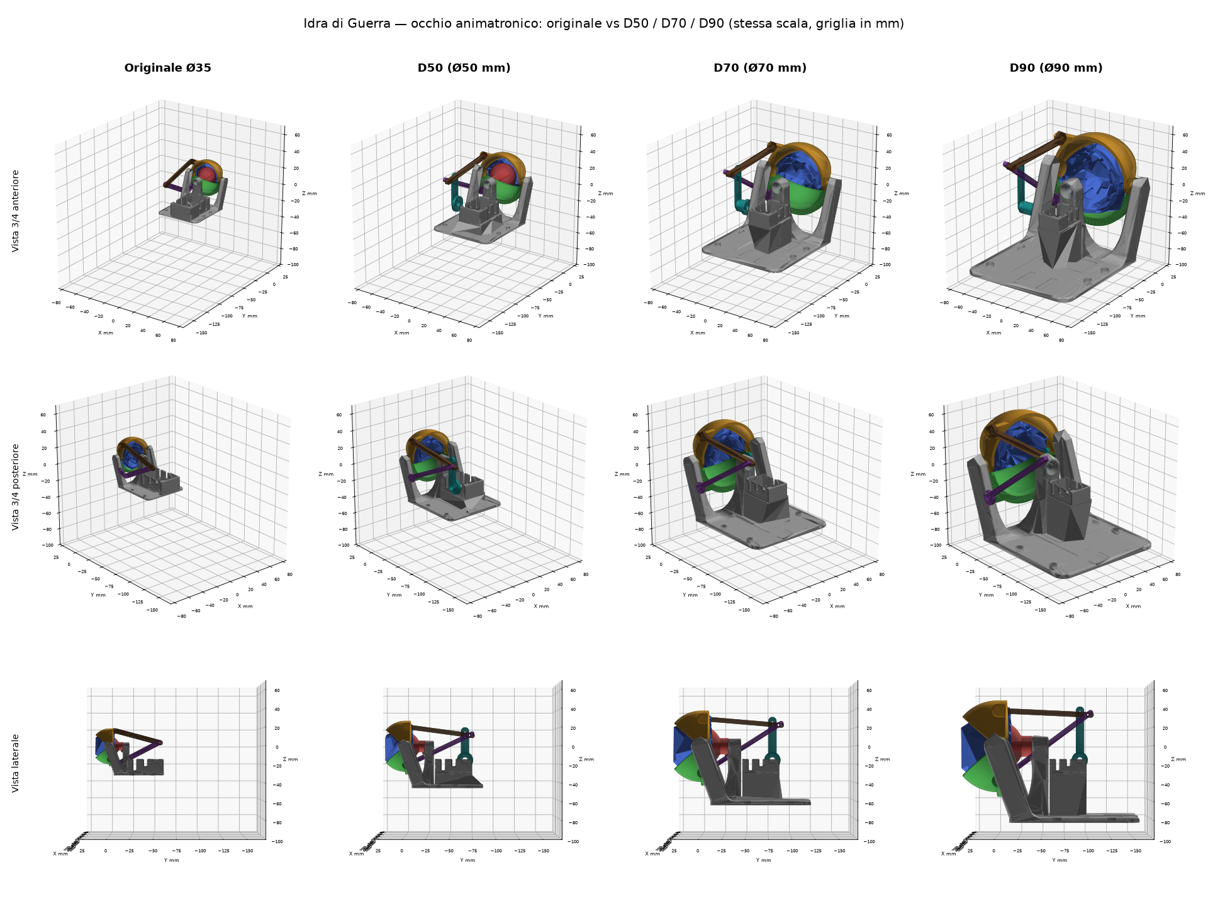
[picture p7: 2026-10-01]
docs/img/confronto_taglie.png

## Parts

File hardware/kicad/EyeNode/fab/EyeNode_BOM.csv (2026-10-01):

Riferimenti | Valore | Footprint | Qta
A1 | Arduino Nano v3 | Module:Arduino_Nano | 1
C1,C2 | 1000uF 10V | Capacitor_THT:CP_Radial_D10.0mm_P5.00mm | 2
C3 | 100nF | Capacitor_SMD:C_1206_3216Metric | 1
C4 | 10uF 50V | Capacitor_SMD:C_1206_3216Metric | 1
C5 | 10uF 16V | Capacitor_SMD:C_1206_3216Metric | 1
D1 | SS34 | Diode_SMD:D_SMA | 1
D2 | SS54 (crowbar inv. pol.) | Diode_SMD:D_SMC | 1
D3 | verde VSERVO | LED_SMD:LED_1206_3216Metric | 1
D4 | blu STATO | LED_SMD:LED_1206_3216Metric | 1
F1 | 0.5A | Fuse:Fuse_1812_4532Metric | 1
F2 | 7.5A blade | Fuse:Fuseholder_Blade_Mini_Keystone_3568 | 1
J1 | 12V IN logica | TerminalBlock_Phoenix:TerminalBlock_Phoenix_MKDS-1,5-2-5.08_1x02_P5.08mm_Horizontal | 1
J2 | 5-6V IN servo | TerminalBlock_Phoenix:TerminalBlock_Phoenix_MKDS-1,5-2-5.08_1x02_P5.08mm_Horizontal | 1
J3 | SERVO A_LR | Connector_PinHeader_2.54mm:PinHeader_1x03_P2.54mm_Vertical | 1
J4 | SERVO A_UD | Connector_PinHeader_2.54mm:PinHeader_1x03_P2.54mm_Vertical | 1
J5 | SERVO A_LID | Connector_PinHeader_2.54mm:PinHeader_1x03_P2.54mm_Vertical | 1
J6 | SERVO B_LR | Connector_PinHeader_2.54mm:PinHeader_1x03_P2.54mm_Vertical | 1
J7 | SERVO B_UD | Connector_PinHeader_2.54mm:PinHeader_1x03_P2.54mm_Vertical | 1
J8 | SERVO B_LID | Connector_PinHeader_2.54mm:PinHeader_1x03_P2.54mm_Vertical | 1
J11 | AUX I2C/A6 | Connector_PinHeader_2.54mm:PinHeader_1x05_P2.54mm_Vertical | 1
R1-R6 | 220 | Resistor_SMD:R_1206_3216Metric | 6
R10,R13 | 1k | Resistor_SMD:R_1206_3216Metric | 2
R11,R12 | 10k | Resistor_SMD:R_1206_3216Metric | 2
SW1 | ADDR | Button_Switch_THT:SW_DIP_SPSTx04_Slide_9.78x12.34mm_W7.62mm_P2.54mm | 1
U1 | R-78E5.0-0.5 | Converter_DCDC:Converter_DCDC_RECOM_R-78E-0.5_THT | 1

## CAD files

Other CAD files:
mechanical/eyes/original/double_compact/Animatronic Eyes - Eyelid_Lower_R.stl
mechanical/eyes/original/single_v4/Animatronic Eyes - Eyelid_Lower_L.stl
mechanical/eyes/scaled/D50/EyeBall_Ball_Joint_D50.stl
mechanical/eyes/scaled/D70/BasePlate_D70.stl
mechanical/eyes/scaled/D90/BasePlate_D90.stl
mechanical/eyes/scaled/double/D50/Linkage_Lower_L_D50.stl
mechanical/eyes/scaled/double/D70/EyeBall_Ball_Joint_D70_x2.stl
mechanical/eyes/scaled/double/D90/EyeBall_Ball_Joint_D90_x2.stl
mechanical/eyes/original/double_compact/Animatronic Eyes - BasePlate.stl
mechanical/eyes/original/single_v4/Animatronic Eyes - Eyelid_Upper_L.stl
mechanical/eyes/scaled/D50/Linkage_Lower_D50.stl
mechanical/eyes/scaled/D70/Linkage_Upper_D70.stl
mechanical/eyes/scaled/D90/EyeBall_Ball_Joint_D90.stl
mechanical/eyes/scaled/double/D50/Linkage_Upper_R_D50.stl
mechanical/eyes/scaled/double/D70/Linkage_Lower_R_D70.stl
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

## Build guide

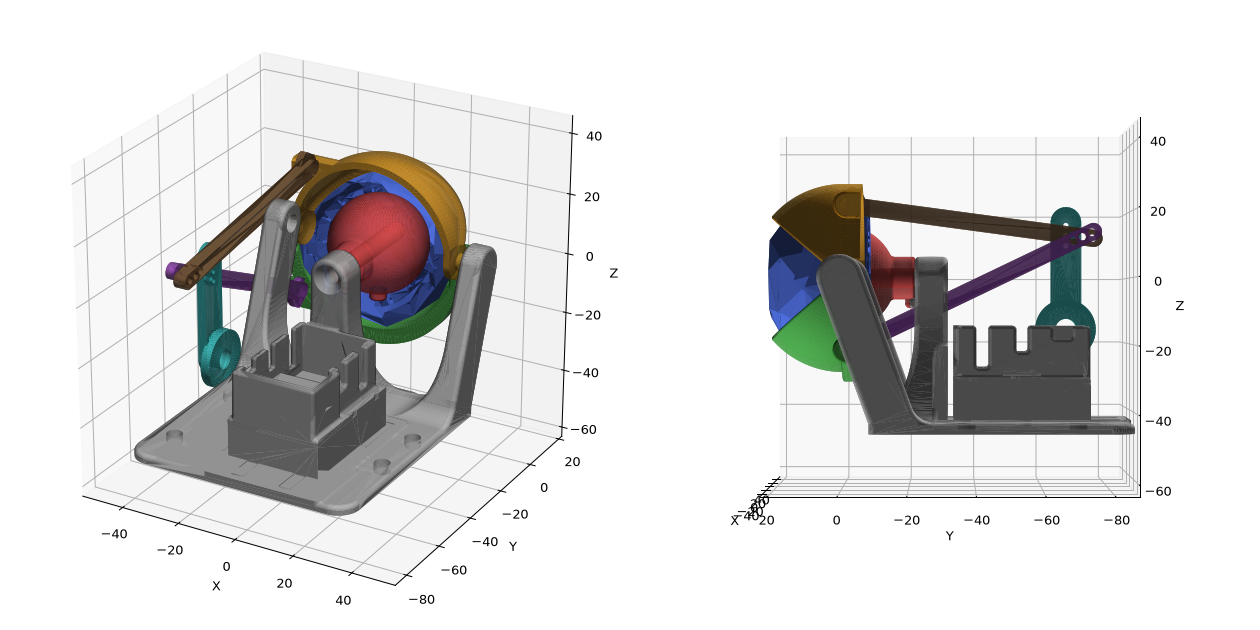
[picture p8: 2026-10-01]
docs/img/assembly_D50.png

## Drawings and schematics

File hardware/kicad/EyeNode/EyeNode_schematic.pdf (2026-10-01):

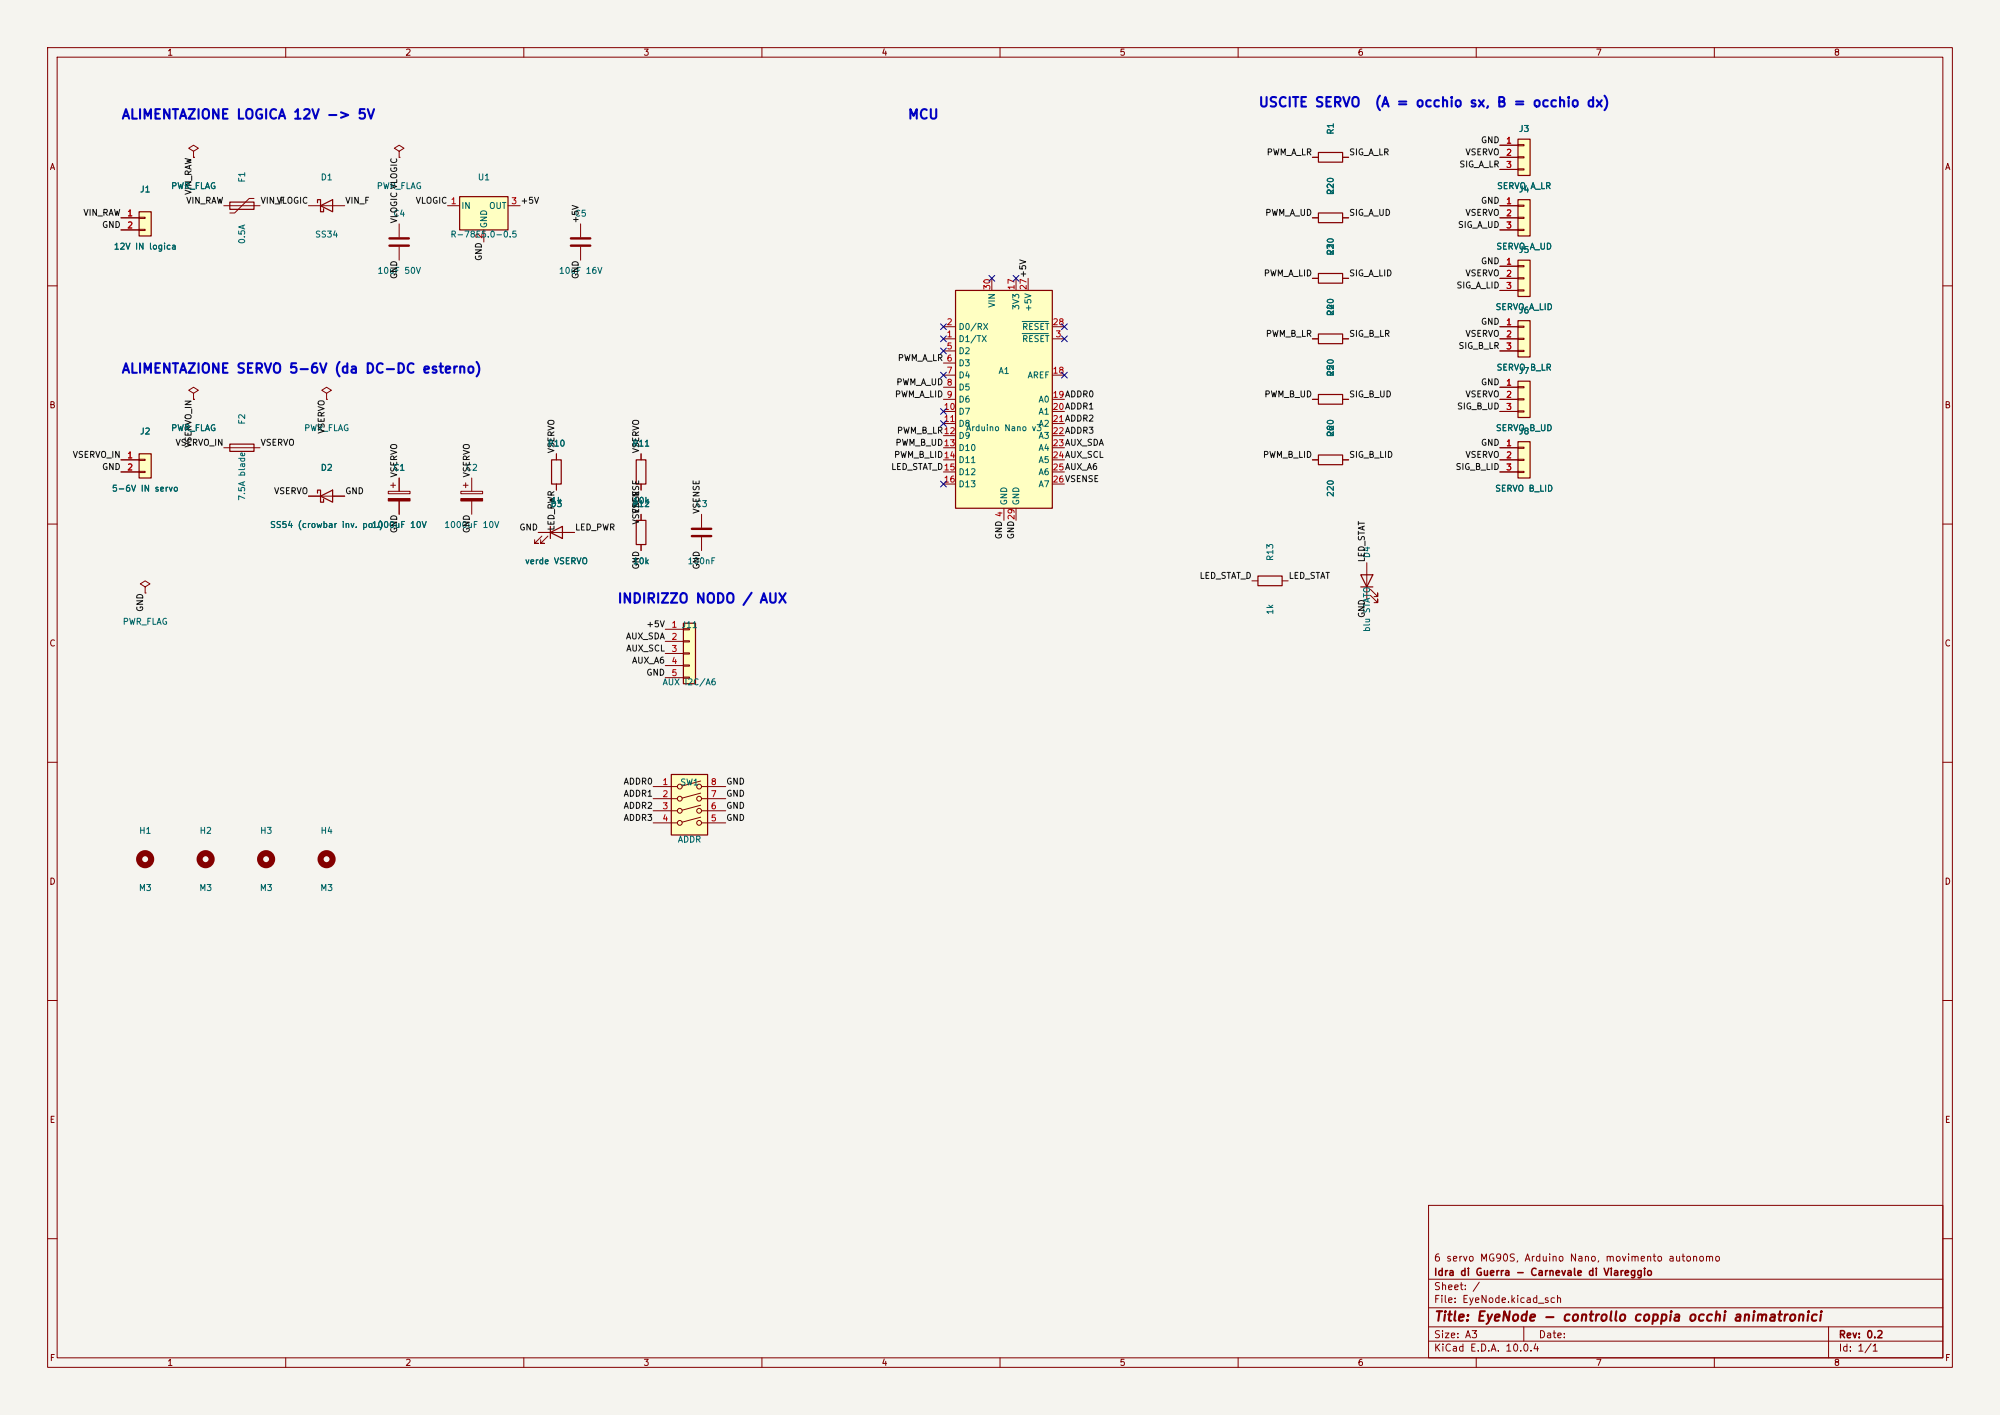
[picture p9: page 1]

USCITE SERVO (A = occhio sx, B = occhio dx)

ALIMENTAZIONE SERVO 5-6V (da DC-DC esterno)

6 servo MG90S, Arduino Nano, movimento autonomo
Idra di Guerra - Carnevale di Viareggio
Sheet: /
File: EyeNode.kicad_sch
Title: EyeNode - controllo coppia occhi animatronici

Size: A3 | Rev: 0.2
KiCad E.D.A. 10.0.4 | Id: 1/1 | F Date:

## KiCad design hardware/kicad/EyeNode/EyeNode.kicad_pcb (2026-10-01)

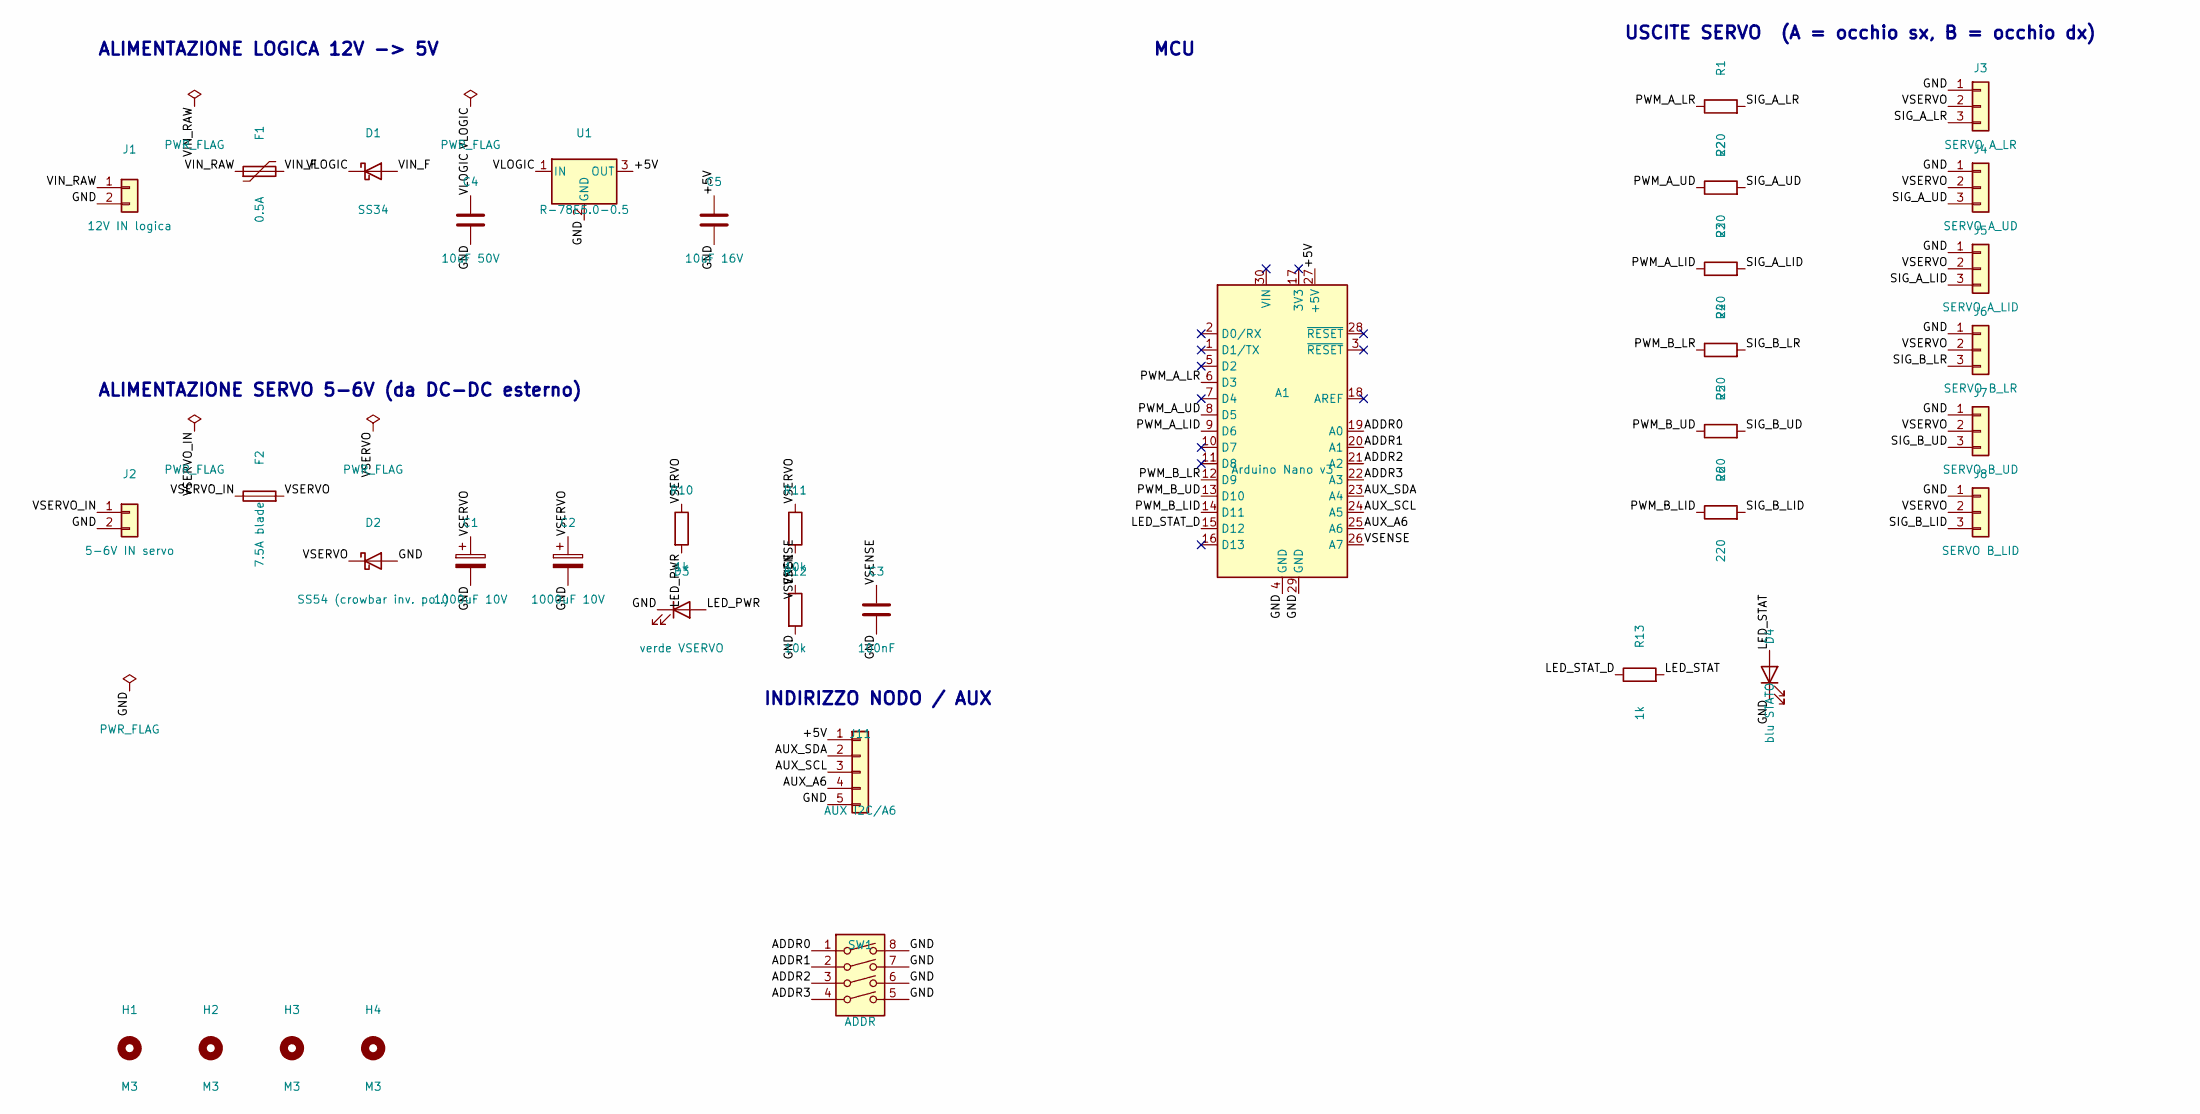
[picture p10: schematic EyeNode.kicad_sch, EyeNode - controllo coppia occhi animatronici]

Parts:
A1: Arduino Nano v3; Arduino_Nano
C1, C2: 1000uF 10V; CP_Radial_D10.0mm_P5.00mm
C3: 100nF; C_1206_3216Metric
C4: 10uF 50V; C_1206_3216Metric
C5: 10uF 16V; C_1206_3216Metric
D1: SS34; D_SMA
D2: SS54 (crowbar inv. pol.); D_SMC
D3: verde VSERVO; LED_1206_3216Metric
D4: blu STATO; LED_1206_3216Metric
F1: 0.5A; Fuse_1812_4532Metric
F2: 7.5A blade; Fuseholder_Blade_Mini_Keystone_3568
H1, H2, H3, H4: M3; MountingHole_3.2mm_M3
J1: 12V IN logica; TerminalBlock_Phoenix_MKDS-1,5-2-5.08_1x02_P5.08mm_Horizont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
J2: 5-6V IN servo; TerminalBlock_Phoenix_MKDS-1,5-2-5.08_1x02_P5.08mm_Horizont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
J3: SERVO A_LR; PinHeader_1x03_P2.54mm_Vertical
J4: SERVO A_UD; PinHeader_1x03_P2.54mm_Vertical
J5: SERVO A_LID; PinHeader_1x03_P2.54mm_Vertical
J6: SERVO B_LR; PinHeader_1x03_P2.54mm_Vertical
J7: SERVO B_UD; PinHeader_1x03_P2.54mm_Vertical
J8: SERVO B_LID; PinHeader_1x03_P2.54mm_Vertical
J11: AUX I2C/A6; PinHeader_1x05_P2.54mm_Vertical
R1, R2, R3, R4, R5, R6: 220; R_1206_3216Metric
R10, R13: 1k; R_1206_3216Metric
R11, R12: 10k; R_1206_3216Metric
SW1: ADDR; SW_DIP_SPSTx04_Slide_9.78x12.34mm_W7.62mm_P2.54mm
U1: R-78E5.0-0.5; Converter_DCDC_RECOM_R-78E-0.5_THT

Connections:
/+5V: A1.27 (+5V), C5.1, J11.1, U1.3 (OUT)
/ADDR0: A1.19 (A0), SW1.1
/ADDR1: A1.20 (A1), SW1.2
/ADDR2: A1.21 (A2), SW1.3
/ADDR3: A1.22 (A3), SW1.4
/AUX_A6: A1.25 (A6), J11.4
/AUX_SCL: A1.24 (A5), J11.3
/AUX_SDA: A1.23 (A4), J11.2
/GND: A1.4 (GND), A1.29 (GND), C1.2, C2.2, C3.2, C4.2, C5.2, D2.2 (A), D3.1 (K), D4.1 (K), J1.2, J2.2, J3.1, J4.1, J5.1, J6.1, J7.1, J8.1, J11.5, R12.2, SW1.5, SW1.6, SW1.7, SW1.8, U1.2 (GND)
/LED_PWR: D3.2 (A), R10.2
/LED_STAT: D4.2 (A), R13.2
/LED_STAT_D: A1.15 (D12), R13.1
/PWM_A_LID: A1.9 (D6), R3.1
/PWM_A_LR: A1.6 (D3), R1.1
/PWM_A_UD: A1.8 (D5), R2.1
/PWM_B_LID: A1.14 (D11), R6.1
/PWM_B_LR: A1.12 (D9), R4.1
/PWM_B_UD: A1.13 (D10), R5.1
/SIG_A_LID: J5.3, R3.2
/SIG_A_LR: J3.3, R1.2
/SIG_A_UD: J4.3, R2.2
/SIG_B_LID: J8.3, R6.2
/SIG_B_LR: J6.3, R4.2
/SIG_B_UD: J7.3, R5.2
/VIN_F: D1.2 (A), F1.2
/VIN_RAW: F1.1, J1.1
/VLOGIC: C4.1, D1.1 (K), U1.1 (IN)
/VSENSE: A1.26 (A7), C3.1, R11.2, R12.1
/VSERVO: C1.1, C2.1, D2.1 (K), F2.2, J3.2, J4.2, J5.2, J6.2, J7.2, J8.2, R10.1, R11.1
/VSERVO_IN: F2.1, J2.1

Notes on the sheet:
ALIMENTAZIONE LOGICA 12V -> 5V
ALIMENTAZIONE SERVO 5-6V (da DC-DC esterno)
MCU
USCITE SERVO (A = occhio sx, B = occhio dx)
INDIRIZZO NODO / AUX

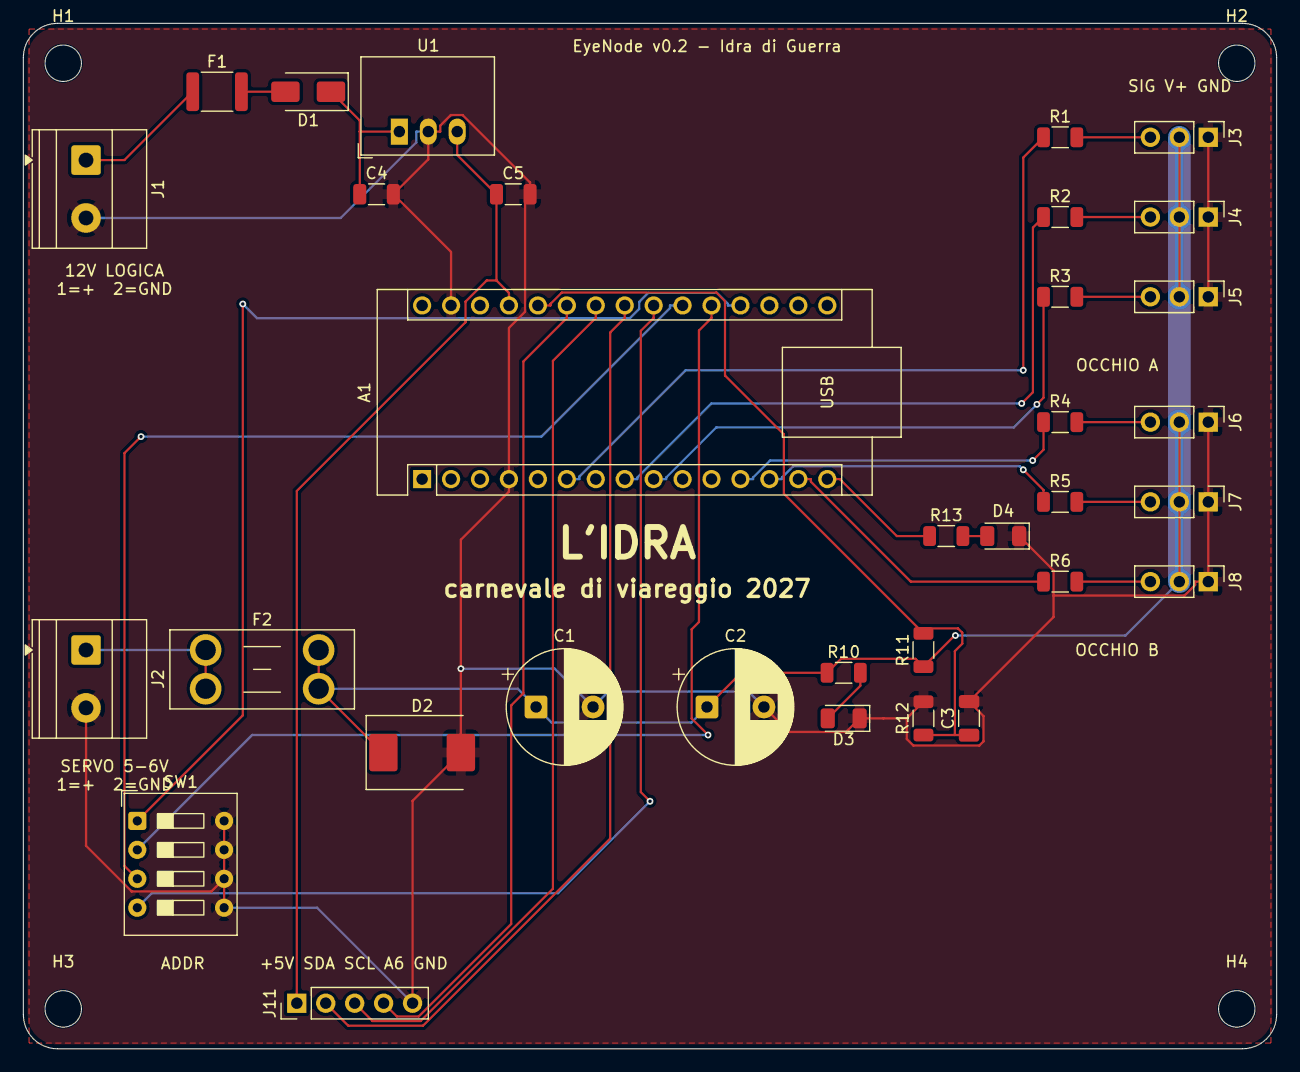
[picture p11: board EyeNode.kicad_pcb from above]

Board: 2 copper layers, 110.0 x 90.0 mm, 37 parts (0 on the bottom side), 30 nets.

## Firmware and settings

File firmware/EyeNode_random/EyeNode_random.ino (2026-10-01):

// =====================================================================
//  EyeNode_random — movimento autonomo e casuale degli occhi di una testa
//  L'Idra, Carnevale di Viareggio 2027 — scheda EyeNode (Arduino Nano)
// =====================================================================
//  Ogni testa e' indipendente: nessun bus, nessun master. Il carattere
//  della testa (velocita', ampiezza, frequenza dei battiti, direzione
//  preferita) viene estratto a caso all'accensione da un seme che
//  dipende dall'indirizzo DIP, da un contatore di accensioni in EEPROM
//  e dal rumore degli ingressi analogici: due teste non si muovono mai
//  allo stesso modo, e la stessa testa cambia a ogni accensione.
//
//  Comportamento:
//    - fissazione di un punto (tempo casuale) con micro-movimenti
//    - saccade (spostamento rapido) verso un nuovo punto, a volte lento
//    - battiti di ciglia casuali, a volte doppi, spesso dopo un grande
//      spostamento; le palpebre seguono lo sguardo su/giu'
//    - "umore" che cambia ogni 1–4 minuti: calmo, curioso, agitato,
//      assonnato
//
//  Seriale 115200: 'c' = tutti i servo al centro e palpebre aperte
//  (per montare le squadrette), 'r' = riprende il movimento casuale,
//  'b' = battito di ciglia, 's' = stato.
//
//  Librerie: solo Servo ed EEPROM (incluse nell'IDE Arduino).
// =====================================================================
#include <Servo.h>
#include <EEPROM.h>
#include <math.h>
#include "config.h"

// ----------------------------------------------------------- pin scheda
const uint8_t PIN_SERVO[2][3] = { {3, 5, 6}, {9, 10, 11} };   // [occhio][sx/dx, su/giu, palpebre]
const uint8_t PIN_ADDR[4] = { A0, A1, A2, A3 };
const uint8_t PIN_LED = 12;
const uint8_t PIN_VSENSE = A7;
const uint8_t PIN_AUX_A6 = A6;
const uint16_t UPDATE_MS = 10;
const int EEPROM_BOOT_ADDR = 0;

enum Axis { LR = 0, UD = 1, LID = 2 };
enum Mode { MODE_RANDOM, MODE_CENTER, MODE_PARKED };

// ----------------------------------------------------------- utilita'
static float frand(float a, float b) { return a + (b - a) * (random(0, 10001) / 10000.0f); }
static bool chance(float p) { return random(0, 10000) < (long)(p * 10000.0f); }
static float clampf(float v, float lo, float hi) { return v < lo ? lo : (v > hi ? hi : v); }
static float easeOutCubic(float t) { t = 1.0f - t; return 1.0f - t * t * t; }
static float easeInOutCubic(float t) {
  if (t < 0.5f) return 4.0f * t * t * t;
  float u = -2.0f * t + 2.0f;
  return 1.0f - u * u * u / 2.0f;
}

// Movimento interpolato da 'from' a 'to' in 'dur' ms
struct Move {
  float from = 0, to = 0, cur = 0;
  uint32_t t0 = 0;
  uint16_t dur = 0;
  bool smooth = false;     // false = saccade (parte veloce), true = lento in/out
  void go(float target, uint16_t ms, bool sm, uint32_t now) {
    from = cur; to = target; t0 = now; dur = ms; smooth = sm;
    if (ms == 0) cur = to;
  }
  bool done(uint32_t now) const { return dur == 0 || now - t0 >= dur; }
  void update(uint32_t now) {
    if (done(now)) { cur = to; return; }
    float t = (now - t0) / (float)dur;
    cur = from + (to - from) * (smooth ? easeInOutCubic(t) : easeOutCubic(t));
  }
};

// ----------------------------------------------------------- carattere e umore
struct Personality {
  float speed, fixScale, blinkScale, rangeLR, rangeUD, biasLR, biasUD, curiosity, vergence, lidOpen;
};

struct Mood { const char *name; float fix, speed, range, blink, lid; uint8_t weight; };
const Mood MOODS[] = {
  // nome        fissaz. veloc. ampiezza battiti palpebre peso
  { "calmo",     1.6f,   0.80f, 0.60f,   1.30f,  0.00f,   30 },
  { "curioso",   1.0f,   1.00f, 1.00f,   1.00f,  0.05f,   40 },
  { "agitato",   0.45f,  1.25f, 1.00f,   0.60f,  0.08f,   20 },
  { "assonnato", 2.0f,   0.60f, 0.50f,   1.80f, -0.35f,   10 },
};
const uint8_t MOOD_CALM = 0, MOOD_SLEEPY = 3, N_MOODS = sizeof(MOODS) / sizeof(MOODS[0]);

// ----------------------------------------------------------- stato
Servo servo[2][3];
uint8_t addr = 0, nEyes = 2;
uint32_t seed = 0;
uint16_t bootCount = 0;
Personality P;
uint8_t mood = 1;
Mode mode = MODE_RANDOM;

Move gazeLR, gazeUD, lid;
float fixLR = 0, fixUD = 0;          // punto fissato (i micro-movimenti ci girano attorno)
float lidLevel = 0.9f;               // palpebre a riposo (filtrate)
uint8_t blinkPhase = 0;              // 0 nessuno, 1 chiusura, 2 chiuse, 3 apertura
uint8_t blinksPending = 0;
uint32_t blinkHoldUntil = 0;
uint32_t nextGazeAt = 0, nextBlinkAt = 0, nextMicroAt = 0, nextMoodAt = 0;
uint32_t lastUpdate = 0;

float vservo = 6.0f, vbatt = 12.8f;
uint32_t lowServoSince = 0, critBattSince = 0;
bool servoLow = false, battLow = false;

// ----------------------------------------------------------- ingressi
uint8_t readAddress() {
  uint8_t a = 0;
  for (uint8_t i = 0; i < 4; i++) {
    pinMode(PIN_ADDR[i], INPUT_PULLUP);
  }
  delay(5);
  for (uint8_t i = 0; i < 4; i++) {
    if (digitalRead(PIN_ADDR[i]) == LOW) a |= (1 << i);   // DIP ON = chiuso a GND = bit 1
  }
  return a;
}

uint32_t makeSeed(uint8_t a) {
  EEPROM.get(EEPROM_BOOT_ADDR, bootCount);
  bootCount++;
  EEPROM.put(EEPROM_BOOT_ADDR, bootCount);
  uint32_t h = 2166136261UL;                               // FNV-1a
  auto mix = [&](uint32_t v) { for (uint8_t i = 0; i < 4; i++) { h ^= (v >> (8 * i)) & 0xFF; h *= 16777619UL; } };
  mix(a);
  mix(bootCount);
  for (uint8_t i = 0; i < 48; i++) {                       // rumore ADC + jitter temporale
    mix(analogRead(PIN_AUX_A6) ^ ((uint32_t)analogRead(PIN_VSENSE) << 10) ^ micros());
    delayMicroseconds(13 + (h & 63));
  }
  return h ? h : 0x1DA2027UL;
}

// ----------------------------------------------------------- carattere / umore
void rollPersonality() {
  P.speed      = frand(0.80f, 1.25f);
  P.fixScale   = frand(0.70f, 1.50f);
  P.blinkScale = frand(0.70f, 1.40f);
  P.rangeLR    = frand(RANGE_LR_MIN, RANGE_LR_MAX);
  P.rangeUD    = frand(RANGE_UD_MIN, RANGE_UD_MAX);
  P.biasLR     = frand(-BIAS_LR_MAX, BIAS_LR_MAX);
  P.biasUD     = frand(-BIAS_UD_MAX, BIAS_UD_MAX);
  P.curiosity  = frand(0.25f, 0.60f);
  P.vergence   = nEyes == 2 ? frand(0.0f, 0.06f) : 0.0f;
  P.lidOpen    = frand(0.75f, 0.95f);
  // direzione preferita + ampiezza non devono superare la corsa calibrata
  P.rangeLR = min(P.rangeLR, 0.95f - fabs(P.biasLR));
  P.rangeUD = min(P.rangeUD, 0.95f - fabs(P.biasUD));
}

void pickMood(uint32_t now) {
  uint16_t total = 0;
  for (uint8_t i = 0; i < N_MOODS; i++) total += MOODS[i].weight;
  long r = random(0, total);
  for (uint8_t i = 0; i < N_MOODS; i++) {
    if (r < MOODS[i].weight) { mood = i; break; }
    r -= MOODS[i].weight;
  }
  if (battLow) mood = MOOD_SLEEPY;
  else if (servoLow) mood = MOOD_CALM;
  nextMoodAt = now + random(MOOD_MIN_MS, MOOD_MAX_MS);
  Serial.print(F("umore: ")); Serial.println(MOODS[mood].name);
}

// ----------------------------------------------------------- comportamento
float lidRest() {
  const Mood &M = MOODS[mood];
  return clampf(P.lidOpen + M.lid + LID_FOLLOW * gazeUD.cur, LID_REST_MIN, 1.0f);
}

uint16_t fixationMs() {
  const Mood &M = MOODS[mood];
  return (uint16_t)clampf(frand(FIX_MIN_MS, FIX_MAX_MS) * P.fixScale * M.fix, 120, 12000);
}

void startBlink(uint32_t now, bool allowDouble) {
  if (blinkPhase) return;
  blinksPending = (allowDouble && chance(DOUBLE_BLINK_PROB)) ? 1 : 0;
  blinkPhase = 1;
  lid.cur = lidLevel;
  lid.go(0.0f, BLINK_CLOSE_MS, false, now);
}

void scheduleBlink(uint32_t now) {
  const Mood &M = MOODS[mood];
  nextBlinkAt = now + (uint32_t)(frand(BLINK_MIN_MS, BLINK_MAX_MS) * P.blinkScale * M.blink);
}

void updateBlink(uint32_t now) {
  lid.update(now);
  switch (blinkPhase) {
    case 1:
      if (lid.done(now)) {
        uint16_t hold = BLINK_HOLD_MS;
        if (mood == MOOD_SLEEPY) hold = (uint16_t)(hold * frand(3.0f, 12.0f));   // palpebre "pesanti"
        blinkHoldUntil = now + hold;
        blinkPhase = 2;
      }
      break;
    case 2:
      if ((int32_t)(now - blinkHoldUntil) >= 0) {
        lid.go(lidRest(), (uint16_t)(BLINK_OPEN_MS / MOODS[mood].speed), true, now);
        blinkPhase = 3;
      }
      break;
    case 3:
      if (lid.done(now)) {
        lidLevel = lid.cur;
        if (blinksPending) { blinksPending--; blinkPhase = 0; startBlink(now, false); }
        else { blinkPhase = 0; scheduleBlink(now); }
      }
      break;
  }
}

void pickGaze(uint32_t now) {
  const Mood &M = MOODS[mood];
  float rLR = P.rangeLR * M.range, rUD = P.rangeUD * M.range;
  float tLR, tUD;
  bool big;
  if (chance(0.08f)) {                         // torna a guardare "davanti"
    tLR = P.biasLR + frand(-0.1f, 0.1f);
    tUD = P.biasUD + frand(-0.1f, 0.1f);
  } else if (chance(P.curiosity)) {            // nuovo punto ovunque nel suo range
    tLR = P.biasLR + frand(-rLR, rLR);
    tUD = P.biasUD + frand(-rUD, rUD);
  } else {                                     // piccolo spostamento vicino
    tLR = fixLR + frand(-0.18f, 0.18f);
    tUD = fixUD + frand(-0.12f, 0.12f);
  }
  tLR = clampf(tLR, P.biasLR - P.rangeLR, P.biasLR + P.rangeLR);   // mai oltre il range della testa
  tUD = clampf(tUD, P.biasUD - P.rangeUD, P.biasUD + P.rangeUD);

  float dist = max(fabs(tLR - gazeLR.cur), fabs(tUD - gazeUD.cur));
  big = dist > 0.5f;
  float speed = P.speed * M.speed * SPEED_SCALE;
  uint16_t dur = (uint16_t)((SACCADE_BASE_MS + SACCADE_PER_UNIT * dist) / speed);
  bool glance = chance(GLANCE_PROB);
  if (glance) dur = (uint16_t)(dur * frand(3.0f, 6.0f));

  gazeLR.go(tLR, dur, glance, now);
  gazeUD.go(tUD, dur, glance, now);
  fixLR = tLR; fixUD = tUD;
  nextGazeAt = now + dur + fixationMs();
  nextMicroAt = now + dur + random(150, 600);

  if (big && !glance && chance(BLINK_AFTER_BIG)) startBlink(now, true);
}

void microMove(uint32_t now) {
  if (MICRO_AMP <= 0) return;
  gazeLR.go(clampf(fixLR + frand(-MICRO_AMP, MICRO_AMP), -1, 1), 45, false, now);
  gazeUD.go(clampf(fixUD + frand(-MICRO_AMP, MICRO_AMP), -1, 1), 45, false, now);
  nextMicroAt = now + random(250, 900);
}

// ----------------------------------------------------------- uscite servo
int toUs(const ServoCal &c, float v) {
  v = clampf(v, -1.0f, 1.0f);
  return v >= 0 ? c.mid + (int)((c.pos - c.mid) * v) : c.mid + (int)((c.mid - c.neg) * v);
}
int lidUs(const LidCal &c, float v) {
  return c.closed + (int)((c.open - c.closed) * clampf(v, 0.0f, 1.0f));
}

void writeEyes(float lr, float ud, float lv) {
  uint8_t ci = addr <= MAX_ADDR ? addr : 0;
  for (uint8_t e = 0; e < nEyes; e++) {
    const EyeCal &cal = CAL[ci][e];
    float v = (e == 0) ? P.vergence : -P.vergence;   // occhi leggermente convergenti
    servo[e][LR].writeMicroseconds(toUs(cal.lr, lr + v));
    servo[e][UD].writeMicroseconds(toUs(cal.ud, ud));
    servo[e][LID].writeMicroseconds(lidUs(cal.lid, lv));
  }
}

void attachAll() {
  for (uint8_t e = 0; e < nEyes; e++)
    for (uint8_t a = 0; a < 3; a++) {
      if (servo[e][a].attached()) continue;
      servo[e][a].attach(PIN_SERVO[e][a], 500, 2500);
      delay(ATTACH_STEP_MS);                            // uno alla volta: meno spunto
    }
}

void detachAll() {
  for (uint8_t e = 0; e < nEyes; e++)
    for (uint8_t a = 0; a < 3; a++) servo[e][a].detach();
}

// ----------------------------------------------------------- tensioni
void readVoltages(uint32_t now) {
  float vs = analogRead(PIN_VSENSE) * (5.0f / 1023.0f) * 2.0f;
  vservo += (vs - vservo) * 0.05f;
  if (vservo < VSERVO_LOW) {
    if (!lowServoSince) lowServoSince = now;
    if (!servoLow && now - lowServoSince > 3000) {
      servoLow = true; mood = MOOD_CALM;
      Serial.println(F("ATTENZIONE: VSERVO bassa, movimento ridotto"));
    }
  } else { lowServoSince = 0; servoLow = false; }

#if BATT_SENSE_ENABLED
  float vb = analogRead(PIN_AUX_A6) * (5.0f / 1023.0f) * BATT_DIVIDER;
  vbatt += (vb - vbatt) * 0.02f;
  battLow = vbatt < BATT_LOW;
  if (battLow && mood != MOOD_SLEEPY && mode == MODE_RANDOM) mood = MOOD_SLEEPY;
  if (mode == MODE_RANDOM && vbatt < BATT_CRIT) {
    if (!critBattSince) critBattSince = now;
    if (now - critBattSince > 10000UL) {               // la testa "si addormenta"
      Serial.println(F("BATTERIA SCARICA: occhi chiusi, servo staccati"));
      writeEyes(0, -0.3f, 0.0f);
      delay(600);
      detachAll();
      mode = MODE_PARKED;
    }
  } else critBattSince = 0;
  if (mode == MODE_PARKED && vbatt > BATT_RESUME) {
    Serial.println(F("batteria ok, riparto"));
    attachAll();
    mode = MODE_RANDOM;
  }
#endif
}

// ----------------------------------------------------------- LED di stato
void updateLed(uint32_t now) {
  bool on;
  if (mode == MODE_CENTER) on = true;
  else if (mode == MODE_PARKED) on = (now % 4000) < 150;
  else if (servoLow || battLow) on = (now % 250) < 60;
  else {                                   // ogni 3 s lampeggia 'addr' volte (identifica la testa)
    uint16_t t = now % 3000;
    uint8_t n = addr ? addr : 1;
    on = t < n * 300u && (t % 300) < 120;
  }
  digitalWrite(PIN_LED, on);
}

// ----------------------------------------------------------- seriale
void printStatus() {
  Serial.print(F("EyeNode addr=")); Serial.print(addr);
  Serial.print(F(" occhi=")); Serial.print(nEyes);
  Serial.print(F(" boot=")); Serial.print(bootCount);
  Serial.print(F(" seed=0x")); Serial.println(seed, HEX);
  Serial.print(F(" carattere: veloc=")); Serial.print(P.speed, 2);
  Serial.print(F(" fissaz=")); Serial.print(P.fixScale, 2);
  Serial.print(F(" battiti=")); Serial.print(P.blinkScale, 2);
  Serial.print(F(" range=")); Serial.print(P.rangeLR, 2); Serial.print('/'); Serial.print(P.rangeUD, 2);
  Serial.print(F(" bias=")); Serial.print(P.biasLR, 2); Serial.print('/'); Serial.print(P.biasUD, 2);
  Serial.print(F(" curiosita=")); Serial.println(P.curiosity, 2);
  Serial.print(F(" umore=")); Serial.print(MOODS[mood].name);
  Serial.print(F(" VSERVO=")); Serial.print(vservo, 2);
#if BATT_SENSE_ENABLED
  Serial.print(F(" VBATT=")); Serial.print(vbatt, 2);
#endif
  Serial.println();
}

void handleSerial(uint32_t now) {
  while (Serial.available()) {
    char c = Serial.read();
    if (c == 'c') { mode = MODE_CENTER; Serial.println(F("CENTRO: sx/dx=0 su/giu=0 palpebre aperte")); }
    else if (c == 'r') {
      if (mode == MODE_PARKED) attachAll();
      mode = MODE_RANDOM; nextGazeAt = now; Serial.println(F("movimento casuale"));
    }
    else if (c == 'b') startBlink(now, false);
    else if (c == 's') printStatus();
  }
}

// ----------------------------------------------------------- setup / loop
void setup() {
  pinMode(PIN_LED, OUTPUT);
  Serial.begin(115200);
  addr = readAddress();
  nEyes = EYES_FOR_ADDR[addr <= MAX_ADDR ? addr : 0];
  seed = makeSeed(addr);
  randomSeed(seed);
  rollPersonality();

  // posizione iniziale scritta PRIMA di agganciare: il primo impulso e' gia' giusto
  gazeLR.cur = P.biasLR; gazeUD.cur = P.biasUD; lidLevel = P.lidOpen;
  writeEyes(gazeLR.cur, gazeUD.cur, lidLevel);
  delay(addr * START_DELAY_PER_ADDR_MS + random(0, 400));   // le teste partono sfasate
  attachAll();

  uint32_t now = millis();
  pickMood(now);
  printStatus();
  nextGazeAt = now + random(300, 2000);
  scheduleBlink(now);
  lastUpdate = now;
}

void loop() {
  uint32_t now = millis();
  handleSerial(now);
  if (now - lastUpdate < UPDATE_MS) return;
  lastUpdate = now;

  readVoltages(now);
  updateLed(now);

  if (mode == MODE_PARKED) return;
  if (mode == MODE_CENTER) { writeEyes(0, 0, 1.0f); return; }

  if ((int32_t)(now - nextMoodAt) >= 0) pickMood(now);

  bool moving = !gazeLR.done(now) || !gazeUD.done(now);
  if (!moving && (int32_t)(now - nextGazeAt) >= 0) pickGaze(now);
  else if (!moving && (int32_t)(now - nextMicroAt) >= 0 && nextGazeAt - now > 150) microMove(now);
  gazeLR.update(now);
  gazeUD.update(now);

  if (!blinkPhase && (int32_t)(now - nextBlinkAt) >= 0) startBlink(now, true);
  updateBlink(now);
  if (!blinkPhase) lidLevel += (lidRest() - lidLevel) * 0.08f;   // palpebre seguono lo sguardo

  writeEyes(gazeLR.cur, gazeUD.cur, blinkPhase ? lid.cur : lidLevel);
}

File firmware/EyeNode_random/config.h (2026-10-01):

// =====================================================================
//  EyeNode — configurazione (unico file da toccare per tarare le teste)
// =====================================================================
//  Lo stesso firmware va caricato su TUTTE le schede: ogni testa si
//  distingue dall'indirizzo impostato sul DIP switch (SW1) e da un seme
//  casuale diverso a ogni accensione. Nessuna sincronizzazione tra teste.
//
//  Convenzione dei valori (indipendente da come e' montato il servo):
//    sx/dx  : -1 = guarda a sinistra della testa, +1 = a destra
//    su/giu : -1 = guarda in basso,               +1 = in alto
//    palpebre: 0 = chiuse,                         1 = tutte aperte
//  Se un servo si muove al contrario basta scambiare neg e pos.
// =====================================================================
#pragma once
#include <stdint.h>

struct ServoCal { int16_t neg, mid, pos; };      // microsecondi a -1, 0, +1
struct LidCal   { int16_t closed, open; };        // microsecondi a 0 e 1
struct EyeCal   { ServoCal lr, ud; LidCal lid; };

// ---------------------------------------------------------------------
//  Teste: indirizzo DIP -> numero di occhi (2 = coppia, 1 = solo canali A)
//  Indice 0 = scheda senza indirizzo (DIP tutto OFF): trattata come coppia.
// ---------------------------------------------------------------------
const uint8_t MAX_ADDR = 4;
const uint8_t EYES_FOR_ADDR[MAX_ADDR + 1] = {
  2,   // 0000  (default / banco prova)
  2,   // 0001  Testa 1
  2,   // 0010  Testa 2
  2,   // 0011  Testa 3
  1,   // 0100  Testa 4 (occhio singolo)
};

// ---------------------------------------------------------------------
//  Calibrazione [indirizzo][occhio A, occhio B] — valori di partenza,
//  da rifinire sul carro con il comando seriale 'c' (centro) e i limiti
//  meccanici reali di ogni occhio. Restare DENTRO la corsa libera: un
//  servo che spinge contro un fermo va in stallo (~0.8 A) e scalda.
// ---------------------------------------------------------------------
#define CAL_DEFAULT_EYE { {1150, 1500, 1850}, {1250, 1500, 1750}, {1100, 1850} }
const EyeCal CAL[MAX_ADDR + 1][2] = {
  { CAL_DEFAULT_EYE, CAL_DEFAULT_EYE },   // 0
  { CAL_DEFAULT_EYE, CAL_DEFAULT_EYE },   // Testa 1
  { CAL_DEFAULT_EYE, CAL_DEFAULT_EYE },   // Testa 2
  { CAL_DEFAULT_EYE, CAL_DEFAULT_EYE },   // Testa 3
  { CAL_DEFAULT_EYE, CAL_DEFAULT_EYE },   // Testa 4 (B non usato)
};

// ---------------------------------------------------------------------
//  Range del movimento casuale (frazione della corsa calibrata, 0..1).
//  Ogni testa all'accensione sceglie a caso un proprio range dentro
//  [MIN, MAX], quindi alcune teste "esplorano" piu' di altre.
// ---------------------------------------------------------------------
const float RANGE_LR_MIN = 0.60f, RANGE_LR_MAX = 1.00f;
const float RANGE_UD_MIN = 0.45f, RANGE_UD_MAX = 0.85f;
const float BIAS_LR_MAX  = 0.25f;   // direzione "preferita" casuale di ogni testa
const float BIAS_UD_MAX  = 0.15f;

// ---------------------------------------------------------------------
//  Tempi (ms). Vengono poi moltiplicati per il carattere della testa e
//  per l'umore del momento, quindi sono valori medi, non fissi.
// ---------------------------------------------------------------------
const uint16_t FIX_MIN_MS        = 350;   // quanto resta fermo a guardare un punto
const uint16_t FIX_MAX_MS        = 2600;
const uint16_t SACCADE_BASE_MS   = 110;   // spostamento rapido dello sguardo
const uint16_t SACCADE_PER_UNIT  = 160;   // + ms per ogni unita' di distanza
const float    GLANCE_PROB       = 0.15f; // prob. di uno spostamento lento (scansione)
const uint16_t BLINK_MIN_MS      = 2500;  // intervallo tra battiti di ciglia
const uint16_t BLINK_MAX_MS      = 7500;
const uint16_t BLINK_CLOSE_MS    = 90;
const uint16_t BLINK_HOLD_MS     = 50;
const uint16_t BLINK_OPEN_MS     = 160;
const float    DOUBLE_BLINK_PROB = 0.15f;
const float    BLINK_AFTER_BIG   = 0.20f; // prob. di sbattere dopo un grande spostamento
const float    MICRO_AMP         = 0.03f; // micro-movimenti durante la fissazione (0 = off)
const float    LID_FOLLOW        = 0.25f; // le palpebre seguono lo sguardo su/giu'
const float    LID_REST_MIN      = 0.30f;
const uint32_t MOOD_MIN_MS       = 60000UL;   // l'umore cambia ogni 1–4 minuti
const uint32_t MOOD_MAX_MS       = 240000UL;

// Scala globale della velocita': < 1 per bulbi grandi/pesanti (D90 ~0.8)
const float SPEED_SCALE = 1.0f;

// ---------------------------------------------------------------------
//  Avvio scaglionato: i servo vengono agganciati uno alla volta e ogni
//  testa parte con un ritardo diverso (meno spunto sulla batteria).
// ---------------------------------------------------------------------
const uint16_t ATTACH_STEP_MS = 120;
const uint16_t START_DELAY_PER_ADDR_MS = 400;
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

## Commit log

2026-10-01 first commit, baseline created
    [Animatronic Eyes - BasePlate.stl, Animatronic Eyes - EyeBall Ball Joint.stl, Animatronic Eyes - Eyeball.stl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]
2026-10-01 changed image and setup
    [EyeNode-B_Cu.gbl, EyeNode-B_Mask.gbr, EyeNode-B_Mask.gbs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]
2026-10-20 EyeMech D85: sedi servo 1:1 per SG90/MG90S
    Le sedi ingrandite di Will (base: Y e palpebre; telaio XAxisA: X) sono
    riempite e dentro c'e' la sede 1:1 del servo vero, albero sull'asse della
    squadretta, orecchie in appoggio con 2 viti M2. Eliminati ServoShell e
    fermi di Will. Sedi palpebre centrate sul mozzo della squadretta.
    Aggiunti anche gli STL di Will estratti e i pezzi gamba.
2026-10-20 Occhi: versione di prova D32, pulizia e riordino cartelle
    - generate_eyemech.py (ex generate_eyemech_D85.py): --small genera la
    versione di prova nella scala di Will (bulbo 32, sedi/squadrette/fermi
    originali, palpebre a 1 servo con quote ridotte e viti M2); la D85
    genera anche i piatti print_A1.
    - Nuove cartelle: eyes/eyemech_D85 (+ print_A1), eyes/eyemech_D32_prova,
    eyes/original/{eyemech_e3.2, morganmanly}, legs/.
    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
2026-10-20 Occhi: assieme X/Y nel render, sede Y sul mozzo della squadretta
    - CoreY, XAxisA e XAxisB montati nell'assieme (posa ricavata dai vincoli:
    perni sull'asse occhi, anelli sotto i bulbi, servo X nel box del CoreY,
    squadretta X sull'albero) con verifica interferenze in posa neutra.
    - Sede del servo Y (D85) presa dal mozzo della VerticalHorn: era 1 mm
    (1:1) troppo alta. Servo X spostato di 0.75 mm nella finestra di
    XAxisA perche' XAxisB passi dietro le orecchie dei servo palpebre.
    - Render con 6 viste: le ultime due mostrano i 4 servo (palpebre, X, Y).
2026-10-20 Occhi D85: box del CoreY con finestra 1:1 per il servo X
    La piastra superiore del box del CoreY e la cavita' delle orecchie erano
    ingrandite come il resto: ora sono riempite, con la finestra 1:1 attorno
    al servo X vero, appoggio sopra le orecchie e fori per le teste delle
    viti M2. Interasse occhi verificato: 200 mm.
2026-10-20 Occhi D85: piatti Bambu A1 tagliati (9 piatti, ~37.5 h, ~1.24 kg PLA)
    Progetti Bambu Studio pronti per la stampa (A1 0.4, 0.20mm Standard,
    PLA Basic, supporti tree auto come nel 3MF di Will) con riepilogo di
    tempi e filamento per piatto.
2026-10-20 Occhi D85: base ridotta, blocchi sedi accorciati (30 h, 0.86 kg)
    La base di Will teneva anche la scheda e i servo posteriori: resta solo la
    striscia con le fessure dei supporti a L e le sedi dei 3 servo (388x80
    invece di 388x253), con 2 chiavette. I blocchi delle sedi si fermano 24 mm
    sotto le orecchie. Le due meta' della base stanno su un piatto: 8 piatti
    A1 invece di 9, da 37.5 h / 1.24 kg a 30.3 h / 0.86 kg di PLA.
2026-10-20 Rinomina la versione piccola in idra_version
    Cartella eyes/idra_version, file idra_version_*.stl, piatti Bambu
    idra_version_Piatto_N.3mf e immagine docs/img/idra_version.png.
    Il generatore usa i nuovi nomi (--small).
2026-10-20 idra_version: tutti i pezzi su un solo piatto A1 (4 h 58 min, 117 g)
    Da 5 piatti raggruppati per tipo a 1 piatto con tutti e 23 i pezzi
    (impacchettamento 2D con rotazioni di 90 gradi, 6 mm tra i pezzi).
    Aggiunto pack_plate.py che rifa' disposizione e slicing con Bambu Studio.
2026-10-20 idra_version: base ridotta senza sedi inutilizzate (3 h 52 min, 76 g)
    La base intera di Will (145x95, con porta-PCB, sedi dei servo posteriori e
    i fermi) era ancora quella originale. Ora e' la striscia 145x30x28 con tre
    blocchi nuovi (parete 3 mm) per i servo delle palpebre e dell'asse Y, senza
    fermi. 20 pezzi su un piatto: da 4 h 58 min / 117 g a 3 h 52 min / 76 g.
    pack_plate.py genera anche l'immagine della disposizione.
2026-10-20 info.txt idra_version: descrizione corretta delle sedi dei servo
2026-10-22 idra_version: base di Will tagliata con spazio PCA9685, LinkB print-in-place
    Base: torna quella di Will (sedi e fermi originali), tagliata a y = -7
    dietro i servo anteriori; dietro, linguetta con 4 distanziali per un
    PCA9685 (fori 55.9 x 19.0, da verificare). Zona ribassata dei servo
    palpebre allungata di 2.5 mm verso il centro. Fermi: Retainer_Single per
    Y, Retainer_Lid (fermo doppio di Will accorciato) per le palpebre, arco
    alzato di 2.5 mm per i servo reali piu' lunghi del nominale.
    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
2026-10-22 D85: base tagliata con PCA9685, servo X corretto, squadrette originali, 5 piatti
    Base: quella di Will ingrandita e tagliata come nella idra_version, con
    linguetta 1:1 per il PCA9685 (fori 55.9 x 19.0 da verificare). Servo,
    PCA9685 e sedi restano 1:1.
    Asse X: lo script montava il servo X al contrario (albero 10 mm fuori
    dalla linea dei perni degli occhi). Ora albero verso gli occhi: le
    linguette degli adattatori entrano nelle tasche dei bulbi e squadretta e
    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
2026-11-10 D85: piatti organizzati per testa (1 completa, 2 in stampa, 3-4 a occhio singolo)
    - eyemech_D85/pezzi/: un STL per pezzo (prima nella cartella principale)
    - Testa_1/: i 5 piatti gia' stampati (ex bambu_A1/)
    - Testa_2/: gia_stampati/ = piatto delle basi; da_stampare/ = tutto il resto senza
    i bulbi (gia' pronti), reincastrato in 3 piatti invece di 4 (~22 h 45 min, ~0.58 kg)
    - Testa_3/4_occhio_singolo/: stesso meccanismo con il solo occhio sinistro (3 servo),
    le due teste incastrate insieme in 4 + 3 piatti invece di 8 (~50 h 30 min, ~1.45 kg)
    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
